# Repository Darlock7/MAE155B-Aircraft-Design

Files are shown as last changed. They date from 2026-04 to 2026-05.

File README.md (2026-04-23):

**MAE 155B Aircraft Design Project Setup and Workflow (Windows)**
Overview

**First-Time Setup on Windows**

**1.	Get Repository Access**

Make sure you have been added as a collaborator on the GitHub repository before starting.

**2.Install Git for Windows**

Link: https://github.com/git-for-windows/git/releases/download/v2.54.0.windows.1/Git-2.54.0-64-bit.exe
Download and install Git. After installation, open PowerShell and verify Git is installed by running:

	git -–version

If installed correctly, it should return a version number.

⸻

**3.	Create an SSH Key**

	mkdir $HOME.ssh
	ssh-keygen -t ed25519 -C “your_email@example.com”

Press Enter through all prompts unless you want a passphrase.

This creates:
	•	Private key: id_ed25519
	•	Public key: id_ed25519.pub

⸻

**4.Add SSH Key to GitHub**

	type $HOME.ssh\id_ed25519.pub

Copy the output.

Go to GitHub → Settings → SSH and GPG keys → New SSH key
Paste and save.

⸻

**5.Test SSH Connection**

	ssh -T git@github.com

Type “yes” if prompted.

You should see a message confirming your username.

⸻

**6.Clone the Repository**

	cd $HOME
	git clone git@github.com:Darlock7/MAE155B-Aircraft-Design.git
	cd MAE155B-Aircraft-Design

⸻

**7.Set Git Name and Email**

	git config –global user.name “Your Name”
	git config –global user.email “your_email@example.com”

⸻

MATLAB Setup
	1.	Open the Repository

Set Current Folder in MATLAB to:

C:\Users\YourUserName\MAE155B-Aircraft-Design

⸻
**2.	Run the Project**

run_project
main

Always run run_project before main.

⸻

**MATLAB Git Configuration (CRITICAL)**

Go to: Home → Settings → MATLAB → Source Control → Git

Set the following:
	•	Enable SSH
	•	Uncheck “Use SSH agent”
	•	Public key file:
C:\Users\YourUserName.ssh\id_ed25519.pub
	•	Private key file:
C:\Users\YourUserName.ssh\id_ed25519

If this is not configured correctly, MATLAB push/pull will fail.

⸻

MATLAB GUI Workflow (Primary Method)

Before Starting Work
	1.	Open MATLAB
	2.	Navigate to the repository folder
	3.	Click Source Control → Pull

⸻

If Pull Fails

This usually means local changes would be overwritten.

Fix:
	1.	Open “View Changes”
	2.	Right-click modified file (e.g., main.m)
	3.	Choose:
	•	Discard Changes (to delete local edits)
	•	Commit Changes (to keep them)
	4.	Try Pull again

⸻

While Working
	•	Edit and save files in MATLAB
	•	Avoid renaming/moving files unless necessary

⸻

After Making Changes (Push)
	1.	Open “View Changes”
	2.	Select modified files
	3.	Enter commit message
	4.	Click Commit
	5.	Click Push

⸻

Required Daily Workflow
	1.	Open MATLAB
	2.	Pull latest changes
	3.	Run run_project
	4.	Run main
	5.	Make changes
	6.	Save files
	7.	Commit
	8.	Push

⸻

PowerShell Fallback (If MATLAB Fails)

**If MATLAB fails (push, pull, SSH issues), use:**

	cd C:\Users\YourUserName\MAE155B-Aircraft-Design
	git pull
	git add .
	git commit -m “your message”
	git push

⸻

Force Pull (Overwrite Local Changes)

If you want to completely overwrite your local files:

git fetch origin
git reset –hard origin/main

WARNING: This deletes all local changes permanently.

⸻

Common Problems
	1.	Git not recognized
Fix: reinstall Git and restart PowerShell.
	2.	Permission denied (publickey)
Fix: verify your SSH key:

type $HOME.ssh\id_ed25519.pub

Ensure it matches GitHub.
	3.	MATLAB cannot connect to SSH agent
Fix: disable SSH agent in MATLAB and manually set key paths.
	4.	Push rejected (remote ahead)
Fix:

git pull

Resolve conflicts if needed, then:

git push
	5.	Merge conflicts
Look for markers like:

<<<<<<< HEAD

Fix the file, then:

git add filename
git commit -m “resolve conflict”
git push

⸻

Best Practice
	•	Use MATLAB GUI for pull, commit, and push
	•	Always pull before starting work
	•	Use PowerShell if MATLAB fails
	•	Do not edit files directly on GitHub unless necessary
	•	Do not commit generated files

⸻

Final Note

This workflow ensures MATLAB GUI works reliably on Windows. PowerShell is always the fallback when GUI operations fail.

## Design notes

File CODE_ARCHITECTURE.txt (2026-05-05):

================================================================================
  MAE 155B AIRCRAFT DESIGN — CODE ARCHITECTURE GUIDE
  Team: Harshil Patel, John Sigafoos, Angel Ochoa, Juan Sanchez,
        Sara Chowdhury, Analisa Veloz
  Last updated: May 2026
================================================================================

This document explains how the codebase is organized, what each file does,
and how data flows from one function to the next. It is written for teammates
who understand the aerodynamics and physics but are less familiar with the
MATLAB code structure.

--------------------------------------------------------------------------------
  QUICK START — HOW TO RUN THE CODE
--------------------------------------------------------------------------------

1. Open MATLAB and set the working directory to the repo root:
      MAE155B-Aircraft-Design/

2. Run:  main.m

   That is the only file you ever need to run manually. It calls everything else.

3. At the top of main.m there are RUN FLAGS (around line 74). These toggle
   optional subsections:

      showPlots      = true/false   — enable/disable all plots
      viewGeometry   = true/false   — open AVL 3D geometry viewer
      runOptimizer   = true/false   — run CMA-ES profit optimizer (6–10 hrs)
      runMonteCarlo  = true/false   — run Monte Carlo sensitivity analysis
      runSweep       = true/false   — run dynamic stability parameter sweep
      runCSopt       = true/false   — run control surface optimizer

   For a quick check run, set all flags to false except showPlots.

--------------------------------------------------------------------------------
  DIRECTORY STRUCTURE
--------------------------------------------------------------------------------

MAE155B-Aircraft-Design/
│
├── main.m                        ← PRIMARY ENTRY POINT. Run this.
├── run_project.m                 ← Adds all src/ folders to MATLAB path
│
├── src/                          ← All analysis functions
│   ├── aerodynamics/             ← Airfoil and aircraft aero
│   ├── geometry/                 ← Wing, fin, fuselage geometry
│   ├── Stability/                ← Static and dynamic stability
│   ├── propulsion/               ← Motor and propeller models
│   ├── energy/                   ← Energy and battery sizing
│   ├── mission/                  ← Flight performance and trajectories
│   └── economics/                ← Profit scoring and optimization
│
├── plotting/                     ← Visualization functions
│
├── data/
│   ├── airfoils/                 ← Airfoil coordinate files (.dat, XFOIL format)
│   ├── models/                   ← Precomputed surrogate databases (.mat)
│   ├── propellers/               ← APC propeller performance tables (.txt)
│   └── reference/                ← CAD parameters and benchmark polars
│
├── AVL/
│   └── Nimbus/                   ← AVL executable + generated geometry files
│       ├── avl352               ← AVL binary (macOS)
│       ├── avl.exe              ← AVL binary (Windows)
│       ├── fw_dyn.avl           ← Flying-wing geometry (auto-generated)
│       ├── fw_dyn.mass          ← CG / inertia input (auto-generated)
│       └── fw_dyn_st.txt        ← Stability output parsed by MATLAB
│
└── outputs/                      ← Generated results (gitignored on some branches)
    ├── main_output.txt
    ├── manufacturing_dimensions.txt
    └── profit_opt_result.mat

--------------------------------------------------------------------------------
  HOW main.m IS ORGANIZED — EXECUTION ORDER
--------------------------------------------------------------------------------

main.m runs top-to-bottom. Here is every major section in order:

  SECTION 1  — Physical constants (g, rho, mu)
  SECTION 2  — User inputs: efficiency, L/D assumption, payload weight/volume,
                mission parameters (range, altitude, cruise speed)
  SECTION 3  — CAD design variables: AR, taper, sweep, fuselage airfoil choice
  SECTION 4  — Drag build-up inputs: fuselage dimensions, wetted areas
  SECTION 5  — Package volume penalty on fe (empty weight fraction)
  SECTION 6  — Derive gross weight Wg and empty weight We from fe and payload
  SECTION 7  — Cargo bay geometry (how big a box fits inside the fuselage airfoil)
  SECTION 8  — Mission energy calculation (climb + cruise + reserve)
  SECTION 9  — Competition profit score J(x) — first-pass using assumed L/D
  SECTION 10 — Mission profile (lap geometry, runway, climb/descent distances)
  SECTION 11 — Propulsion analysis (thrust curve from motor KV + APC propeller)
  SECTION 12 — CTOL preliminary sizing (wing loading vs. thrust-to-weight diagram)
  SECTION 13 — Monte Carlo sensitivity analysis (optional)
  SECTION 14 — Design lift coefficient at cruise
  SECTION 15 — Wing geometry (span, root/tip chord, MAC, control surface coords)
  SECTION 16 — Airfoil analysis (load surrogate database, evaluate at cruise Re)
  SECTION 17 — Airfoil polar plots
  SECTION 18 — Twist function (Panknin method for required washout)
  SECTION 19 — Vertical stabilizer / winglet geometry
  SECTION 20 — Spanwise aerodynamic estimate (lift distribution)
  SECTION 21 — Aircraft drag polar (CD0 build-up, CL vs alpha, L/D)
  SECTION 22 — Aircraft mass properties (CG, inertia tensor from all components)
  SECTION 23 — Unloaded (no payload) CG and mass
  SECTION 24 — CG position as % MAC
  SECTION 25 — Updated performance state (actual stall speed, cruise speed)
  SECTION 26 — Static stability analysis (neutral point, static margin %)
  SECTION 27 — 3D geometry plot
  SECTION 28 — V-n diagram (maneuver envelope)
  SECTION 29 — Gust load overlay
  SECTION 30 — Dynamic stability via AVL (eigenvalues, short period, phugoid,
                Dutch roll, roll subsidence, spiral mode)
  SECTION 31 — SM correction advisor (where to move the battery for target SM)
  SECTION 32 — Control surface sizing (trim deflection, max load factor, turn radius)
  SECTION 33 — Control surface optimizer (optional)
  SECTION 34 — Dynamic stability sweep (optional)
  SECTION 35 — CMA-ES profit optimizer (optional, 6–10 hrs)
  SECTION 36 — Structure sizing
  SECTION 37 — Profit re-evaluation with actual physics (final sanity check)

--------------------------------------------------------------------------------
  WHAT EACH SOURCE FILE DOES
--------------------------------------------------------------------------------

---- AERODYNAMICS (src/aerodynamics/) ----

  aeroPolarAircraft.m
    Input:  wing geometry (AR, Sref, MAC, sweep), airfoil data (Cla, alphaL0,
            Clmax, Cm0 for root and tip), drag build-up inputs
    Output: aircraft CL(alpha), CD(alpha), L/D(alpha), cruise CL/CD/L-D,
            stall alpha, CDo breakdown (wing/body/fin)
    What it does: Builds the whole-aircraft drag polar using the parabolic
    model CD = CD0 + CL²/(pi*e*AR). CD0 is computed from a Raymer-style
    skin-friction and form-factor drag build-up.

  loadAirfoilSurrogateDB.m
    Input:  repoRoot (path to repo)
    Output: airfoilDB struct
    What it does: Loads data/models/airfoilDB.mat into MATLAB. This .mat file
    contains precomputed XFOIL results for all airfoils at many Reynolds numbers.

  evaluateAirfoilSurrogate.m
    Input:  airfoilDB, airfoil name (e.g. 'e222.dat'), Reynolds number
    Output: Cla, alphaL0, Cm0, Clmax, best L/D interpolated at that Re
    What it does: Interpolates from the precomputed database so we do not need
    to run XFOIL at runtime (which is slow and can fail).

  buildAirfoilSurrogates.m
    What it does: Offline tool — runs XFOIL on every airfoil in data/airfoils/
    across a grid of Reynolds numbers and saves airfoilDB.mat. Only needs to
    be re-run if you add a new airfoil.

  twistFunctionPanknin.m
    Input:  b, AR, c_root, c_tip, sweep, alphaL0 root/tip, Cm0 root/tip,
            CL_design, twist_root_deg (user-set washout at root)
    Output: full spanwise twist distribution, geometric and aerodynamic twist
    What it does: Uses the Panknin method (from class slides) to compute how
    much twist the wing needs across the span to satisfy the pitching moment
    and lift requirements. The optimizer controls twist_root_deg; this function
    computes the required tip twist.

  spanwiseAeroEstimate.m
    Input:  wing geometry + twist distribution + airfoil properties
    Output: spanwise section CL, local lift, root/tip effective alpha
    What it does: Piecewise estimate of how lift is distributed along the span.

---- GEOMETRY (src/geometry/) ----

  wingGeometryDesign.m
    Input:  S_ref [m²], AR, taper ratio, sweep_c4 [deg], xLE_root, y_root
    Output: b, c_root, c_tip, MAC, xLE_tip, xLE_MAC, x_c4_MAC, semiSpan,
            control surface geometry (span stations, area)
    What it does: From the four main planform parameters, computes every chord,
    position, and sweep angle you need. This is the source of truth for all
    geometric quantities used downstream.

  verticalSurfaceDesign.m
    Input:  AR_v, taper_v, sweep_c4_v, tail volume coefficient c_v,
            wing reference geometry (for moment arm)
    Output: S_v, b_v, c_root_v, c_tip_v, MAC_v, all LE/TE positions,
            rudder geometry
    What it does: Sizes the winglet/vertical stabilizer using a tail volume
    coefficient approach, then computes the full trapezoidal fin geometry.

  cargoBayGeometry.m
    Input:  Lf (fuselage length), Wf (fuselage width), airfoil file
    Output: maximum rectangle width and height that fits inside the airfoil
            cross-section, cargo bay volume [m³]
    What it does: Finds the largest rectangular box that fits inside the
    fuselage airfoil shape. Volume = cross-section area × spanwise depth (Wf).

---- STABILITY (src/Stability/) ----

  dynamicStabilityAVL.m
    Input:  mass, inertia tensor, CG, wing geometry, fin geometry, aero data,
            cruise conditions
    Output: full eigenvalue set, mode damping ratios and frequencies,
            handling quality level (MIL-STD), control derivatives
    What it does: This is the most complex function. It:
      1. Writes the AVL geometry file (.avl) from MATLAB inputs
      2. Writes the mass/inertia file (.mass)
      3. Runs the AVL binary (avl352 on Mac, avl.exe on Windows) via system()
      4. Parses AVL's stability derivative output (CL_alpha, Cm_alpha, Cm_q, etc.)
      5. Performs eigenanalysis to find the 4 longitudinal and 4 lateral modes
      6. Classifies modes: Short Period, Phugoid, Dutch Roll, Roll Subsidence, Spiral
      7. Rates handling qualities per MIL-STD-1797 (Level 1/2/3)

  aircraftMassProperties.m
    Input:  cadBodies (CAD-derived mass components), pointMasses (discrete items:
            motor, battery, receiver, payload, servos, etc.)
    Output: total mass, CG [x,y,z], full 3×3 inertia tensor about CG
    What it does: Combines all mass contributions and applies the parallel-axis
    theorem to compute the inertia tensor about the aircraft CG.

  staticStabilityAnalysis.m
    Input:  CG position, neutral point, MAC, xLE_MAC
    Output: static margin [%], stability band check, CG shift with/without payload
    What it does: Computes SM = (x_NP - x_CG) / MAC. The neutral point in this
    function comes from the simplified assumption x_NP = x_c4_MAC (25% MAC).
    Note: AVL gives a more accurate neutral point — trust AVL's SM over this one.

  makePointMass.m
    Input:  name (string), mass [kg], position [x, y, z] [m]
    Output: struct with those fields
    What it does: Simple helper to create a component entry for mass properties.
    Used throughout main.m to define motor, battery, payload, servos, etc.

  controlSurfaceSizing.m
    Input:  AVL control derivatives (Cmde, Clda, Cnda, Clp), cruise conditions,
            wing geometry, mass
    Output: trim elevon deflection, max load factor, min turn radius, roll rate,
            hinge moments for servo sizing
    What it does: Converts AVL's dimensionless derivatives into real performance
    numbers — how many degrees the elevon must deflect to trim, how fast it rolls.

---- PROPULSION (src/propulsion/) ----

  propulsionAnalysis.m
    Input:  motor KV [RPM/V], Rm [ohm], I0 [A], battery voltage,
            propeller name (e.g. '10x4.5MR'), speed vector V_vec
    Output: thrust curve T(V), power curve P(V), static thrust T_static,
            static current
    What it does: Uses the APC propeller data tables in data/propellers/ plus
    the motor electrical model (back-EMF) to compute how much thrust the
    motor/prop combination produces at any flight speed.

---- ENERGY (src/energy/) ----

  energyCalc.m
    Input:  Wg [N], eta_p (propulsion efficiency), LD (lift-to-drag),
            delta_h [m] (climb altitude), R_cruise [m], reserve_factor
    Output: E_climb, E_cruise, E_f (total mission energy), E_design (with reserve)
    What it does: Simple physics energy calculation.
      E_climb  = Wg * delta_h / eta_p
      E_cruise = (Wg / LD) * R_cruise / eta_p
    These are used directly in the profit function.

---- MISSION (src/mission/) ----

  missionProfileCigar.m
    Input:  runway length, pattern dimensions, cruise speed, climb/descent angles
    Output: lap length, flight times for each phase, liftoff/touchdown positions
    What it does: Models the "cigar-shaped" competition course (two straights
    connected by 180° turns) and computes total mission geometry.

  solveCruiseSpeed.m
    Input:  rho, weight, Sref, drag polar, thrust curve
    Output: actual cruise speed where T_available = D
    What it does: Finds the speed where the propeller thrust equals the aircraft
    drag. This is the actual cruise speed, which may differ from the design speed.

  updatePerformanceState.m
    Input:  all aerodynamic and propulsion data
    Output: actual stall speed, takeoff speed, cruise speed, max climb rate
    What it does: Given the fully-computed aircraft (not the simplified early
    estimate), re-derives all performance numbers for a final sanity check.

---- ECONOMICS (src/economics/) ----

  profitPerUnitTime.m
    Input:  Wp [N] (payload weight), Vp [m³] (payload volume),
            Ef [J] (total energy × 20 flights), Wg [N], Tf [s] (time × 20 flights)
    Output: J [$/s] — competition profit score
    What it does: Implements the MAE155B competition scoring function exactly.
    This is the number you want to maximize. J increases with heavier payload,
    more payload volume, and lighter/more efficient aircraft.

  profitOptimization.m
    Input:  optIn struct with all mission/physics context + bounds + settings
    Output: optimal design vector (13 variables), best J achieved, convergence history
    What it does: Runs CMA-ES (Covariance Matrix Adaptation Evolution Strategy),
    a gradient-free global optimizer, to find the combination of AR, taper, sweep,
    twist, wing loading, fuselage size, fin shape, and cruise speed that maximizes J.
    Each candidate design calls wingGeometryDesign → airfoil surrogate → twist →
    vertical surface → mass model → drag polar → AVL stability → profit score.
    Constraints enforced: stall speed ≤ 12 m/s, static margin 5–13%,
    takeoff ground roll ≤ 138 m, climb T/W feasible, turn T/W feasible,
    winglet chord ≤ 1.2× wing tip chord, wingspan ≤ 2.5 m.
    Runtime: 6–10 hours on a fast machine with parallel workers.

  monteCarloProfitSensitivity.m
    Input:  baseline design + uncertainty ranges for each variable
    Output: distribution of J, sensitivity to each parameter
    What it does: Randomly perturbs design variables within tolerances and
    computes J for each sample. Shows which parameters most affect profit.

---- PLOTTING (plotting/) ----

  plotAircraftGeometry3D.m
    What it does: Draws the full 3D aircraft — wing, fins, fuselage, CG markers
    (loaded and unloaded), and component point masses. Most useful visual check.

  preliminarySizingCTOL.m
    What it does: Draws the T/W vs W/S carpet plot showing stall, climb, turn,
    and takeoff constraint lines. The design point sits where all constraints
    are satisfied with minimum T/W.

  plotVNDiagram.m
    What it does: Draws the velocity-load factor (V-n) diagram showing the
    maneuver envelope, stall boundary, and gust load curves.

--------------------------------------------------------------------------------
  DATA FLOW SUMMARY
--------------------------------------------------------------------------------

This shows what each function needs from others:

  Inputs (user)
       |
       v
  wingGeometryDesign  ──────────────────────────────────────────────────────┐
       |  b, c_root, c_tip, MAC, xLE positions                              |
       v                                                                     |
  evaluateAirfoilSurrogate (uses airfoilDB.mat at cruise Re)               |
       |  Cla, alphaL0, Cm0, Clmax for root and tip                        |
       v                                                                     |
  twistFunctionPanknin                                                      |
       |  spanwise twist distribution                                        |
       v                                                                     |
  aeroPolarAircraft                                                         |
       |  CL(alpha), CD(alpha), L/D, cruise CL/CD, CD0 breakdown           |
       v                                                                     |
  energyCalc(Wg, L/D, ...)     propulsionAnalysis(motor, prop, ...)        |
       |  E_climb, E_cruise             |  T(V) thrust curve                |
       v                               v                                    |
  profitPerUnitTime(Wp, Vp, Ef, Wg, Tf)                                    |
       |  J [$/hr]                                                           |
       v                                                                     |
  (optimization target)                                                     |
                                                                            |
  aircraftMassProperties(all components)  ◄──── verticalSurfaceDesign ◄───┘
       |  total mass, CG, inertia tensor
       v
  dynamicStabilityAVL(geometry + mass + aero)
       |  eigenvalues, damping, frequencies, SM from AVL
       v
  controlSurfaceSizing(AVL derivatives + geometry)
       |  trim deflection, max load factor, servo hinge moments
       v
  updatePerformanceState(aero + propulsion + mass)
       |  actual stall speed, actual cruise speed, climb rate
       v
  [Final output to screen + plots]

--------------------------------------------------------------------------------
  THE OPTIMIZATION LOOP (profitOptimization.m)
--------------------------------------------------------------------------------

Every time the optimizer evaluates one candidate design, it runs this
internal mini-pipeline:

  1. Decode 13 design variables from normalized [0,1] space to physical units
  2. Estimate gross weight from empty-weight fraction model
  3. wingGeometryDesign  → planform
  4. Evaluate airfoil surrogates at cruise Re for root and tip
  5. twistFunctionPanknin → required washout
  6. verticalSurfaceDesign → fin geometry
  7. Check geometric feasibility (tip chord, wingspan, fin height, fin chord)
  8. Scale structural masses
  9. aircraftMassProperties → CG + inertia
  10. aeroPolarAircraft → L/D and CD0
  11. Check stall speed ≤ 12 m/s
  12. Check takeoff ground roll ≤ 138 m
  13. Check climb T/W feasible at V_climb = 13 m/s
  14. Check turn T/W feasible at V_turn = 13 m/s
  15. dynamicStabilityAVL → static margin
  16. Check SM in [5%, 13%] band
  17. energyCalc + profitPerUnitTime → J
  18. Apply soft penalties for poor dynamic stability modes
  19. Return -J as the objective (CMA-ES minimizes, we maximize J)

  If any hard constraint (steps 7–16) is violated, the design is rejected
  immediately (returns 1e6) without computing J. This saves time.

  With lambda ≈ 26 candidates per generation and 500 generations,
  the optimizer evaluates ~13,000 designs. Each design takes ~2 s
  (dominated by AVL). Total runtime: 6–10 hours with parfor.

--------------------------------------------------------------------------------
  AVL INTEGRATION
--------------------------------------------------------------------------------

AVL (Athena Vortex Lattice) is an external program by Mark Drela (MIT).
It computes aerodynamic stability derivatives using a vortex-lattice method,
which is significantly more accurate than our simplified analytical formulas.

How MATLAB uses AVL:

  1. dynamicStabilityAVL.m writes three files based on the current design:
       AVL/Nimbus/fw_dyn.avl    ← geometry: wing panels, fin panels, control deflections
       AVL/Nimbus/fw_dyn.mass   ← mass, CG location, inertia tensor
       AVL/Nimbus/fw_dyn.run    ← operating condition: V, rho, alpha_trim

  2. MATLAB calls:   system('./avl352 < fw_dyn_cmd.txt > fw_dyn_st.txt')
     This runs AVL, feeds it commands via the .txt file, and captures output.

  3. MATLAB reads fw_dyn_st.txt and parses numbers using regular expressions:
       CLa, Cma (lift and pitch moment slopes)
       Cmq      (pitch damping)
       CYb, Clb, Cnb (lateral-directional derivatives)
       Eigenvalues (complex pairs for longitudinal and lateral modes)

  4. From the eigenvalues, MATLAB classifies each mode:
       Short Period:   high-frequency, well-damped pitch oscillation (want zeta > 0.35)
       Phugoid:        low-frequency speed/pitch exchange (want zeta > 0)
       Dutch Roll:     coupled yaw-roll oscillation (want zeta*wn > 0.19)
       Roll Subsidence: first-order roll decay (want tau < 1.0 s)
       Spiral:         slow roll divergence (want t_half > 20 s)

  Important: The "Static Margin" reported by AVL is the authoritative value.
  The simpler static margin in the main.m static stability section uses a
  rough neutral point at 25% MAC, which is less accurate.

--------------------------------------------------------------------------------
  AIRFOIL SURROGATE DATABASE
--------------------------------------------------------------------------------

Running XFOIL every time would be too slow (2–5 s per airfoil per Re).
Instead, we precompute all results offline:

  buildAirfoilSurrogates.m  ← run once, saves data/models/airfoilDB.mat

At runtime, main.m calls:
  loadAirfoilSurrogateDB(repoRoot)  ← loads the .mat file (fast)
  evaluateAirfoilSurrogate(db, 'e222.dat', Re_root)  ← interpolates at Re

The database stores for each airfoil at each Reynolds number:
  Cla        [1/deg]   — lift curve slope
  alphaL0    [deg]     — zero-lift angle of attack
  Cm0        [-]       — pitching moment at zero lift
  Cl_max     [-]       — maximum lift coefficient
  best_LD    [-]       — maximum L/D

The optimizer uses this database internally so AVL calls (not XFOIL) are the
bottleneck during optimization.

--------------------------------------------------------------------------------
  ADDING A NEW AIRFOIL
--------------------------------------------------------------------------------

1. Put the airfoil .dat file in data/airfoils/ (XFOIL format: two columns x/c, y/c)

2. Open buildAirfoilSurrogates.m and add the filename to the airfoil list

3. Run buildAirfoilSurrogates.m once — this regenerates airfoilDB.mat

4. In main.m, change:
      airfoilRootName = 'your_new_airfoil.dat';
   or
      airfoilTipName  = 'your_new_airfoil.dat';

5. For the fuselage airfoil, add an entry to the airfoilFileMap struct in main.m
   and change fuselageAirfoil = 'your_new_airfoil_name';

--------------------------------------------------------------------------------
  MASS PROPERTIES — HOW COMPONENTS ARE DEFINED
--------------------------------------------------------------------------------

Every physical object on the aircraft is entered as either:

  (a) A CAD body from massIn.cadBodies:
      These come from Onshape. Each CAD body has a measured mass and CG
      from the CAD model. The cadMass struct is populated near the top of
      the mass properties section in main.m.

  (b) A discrete point mass using makePointMass():
      comp(end+1) = makePointMass('Motor', 0.085, [0.0, 0.0, 0.0]);
      comp(end+1) = makePointMass('Battery', 0.150, [0.551, 0.0, -0.009]);
      comp(end+1) = makePointMass('Payload', 0.800/9.81*9.81, [x, y, z]);
      Arguments: name (string), mass [kg], position [x, y, z] in meters
                 x=0 is motor, x increases aft toward tail

  aircraftMassProperties() combines all of these, applies the parallel-axis
  theorem, and returns the total mass, CG, and inertia tensor.

  To move the battery for static margin correction:
  Find the line with 'B1 Main Battery' and change the x-coordinate.
  The SM Correction Advisor at the bottom of main.m tells you what x to use.

--------------------------------------------------------------------------------
  UNITS CONVENTION
--------------------------------------------------------------------------------

  All quantities in SI unless otherwise noted.
  Length:      meters [m]
  Mass:        kilograms [kg]
  Force:       Newtons [N]
  Angle:       degrees [deg] at input/output; radians inside stability functions
  Speed:       meters per second [m/s]
  Pressure:    Pascals [Pa]
  Energy:      Joules [J]
  Power:       Watts [W]
  Area:        square meters [m²]
  Volume:      cubic meters [m³]  (multiply by 1000 for liters)
  Profit J:    dollars per second [$/s]  (multiply by 3600 for $/hr)

  The competition scoring function expects:
    Ef in [J] (total energy over 20 flights)
    Tf in [s] (total time over 20 flights)
  The x20 scaling is applied in main.m before calling profitPerUnitTime().

--------------------------------------------------------------------------------
  COMMON DEBUGGING TIPS
--------------------------------------------------------------------------------

Q: main.m crashes with "file not found" on airfoilDB.mat
A: Run buildAirfoilSurrogates.m once to generate the database.

Q: AVL gives wrong static margin
A: Check that the battery x-position in the mass properties section matches
   what the SM Correction Advisor recommends. Also verify that the .mass file
   CG printed in the AVL output matches main.m's aircraftMassProperties output.

Q: Optimizer returns -$1.94/hr or clearly wrong results
A: Workers have cached old bytecode. Run:
     delete(gcp('nocreate')); clear functions;
   before profitOptimization(). This is already in main.m when runOptimizer=true.

Q: Stall speed is above 12 m/s
A: Wing loading W/S is too high. Either increase S_ref (lower WS in optimizer
   bounds) or reduce gross weight.

Q: Feasible@climb = 0 in CTOL sizing
A: Check that V_climb in the mission struct is above the design stall speed.
   The CTOL sizing code checks thrust at V_climb against the T/W required for
   the governing constraint — if V_climb < V_stall, the aircraft cannot fly
   at that speed and the check fails.

Q: "pattern not found: CDa" warning from dynamicStabilityAVL
A: This is cosmetic. AVL does not output CDa in all run configurations.
   The code handles this gracefully and the warning does not affect results.

--------------------------------------------------------------------------------
  DESIGN VARIABLES CONTROLLED BY THE OPTIMIZER
--------------------------------------------------------------------------------

  Index  Variable             Units   Lower  Upper
  ─────  ─────────────────────────────────────────────────────
    1    AR                   [-]     4.0    10.0
    2    Taper ratio          [-]     0.50   0.80
    3    Wing sweep (c/4)     [deg]   0.0    35.0
    4    Root twist           [deg]  -3.0   -1.0    (forced washout)
    5    Wing loading W/S     [N/m²]  20.0   90.0
    6    xLE root             [m]     0.030  0.300
    7    Vertical fin AR      [-]     2.00   2.50
    8    Vertical fin taper   [-]     0.30   0.70
    9    Vertical fin sweep   [deg]   20.0   45.0
   10    Cruise speed         [m/s]   20.0   28.0
   11    Payload volume Vp    [m³]    0.001  0.030
   12    Fuselage half-width  [m]     0.050  0.200
   13    Fuselage length      [m]     0.600  1.000

  When the optimizer finishes, it prints a block labeled
  "--- Update main.m with these values ---"
  Copy those values into the corresponding lines in main.m and re-run.

================================================================================
  END OF DOCUMENT
================================================================================

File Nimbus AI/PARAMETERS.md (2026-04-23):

# Aircraft Design Parameters

This file is the single source of truth for all fixed design parameters, measured values, and data file references. Update it as new information becomes available. Claude reads this before any physics analysis or code work.

All values sourced from `main.m` unless otherwise noted.

---

## Mission Requirements

| Parameter | Value | Unit | Notes |
|---|---|---|---|
| Payload mass | 800 | g | Wp_g |
| Payload weight | 7.848 | N | Wp = (800/1000) × 9.81 |
| Payload volume (actual) | 0.002 | m³ | Vp |
| Payload volume (reference) | 0.001 | m³ | Vp_ref — penalty baseline |
| Volume scaling ratio (VPS) | 2.0 | — | Vp / Vp_ref |
| Cruise speed | 20 | m/s | V_cruise |
| Cruise range | 18000 | m | R_cruise |
| Climb altitude | 120 | m | delta_h |
| Flight time (measured, 1 lap) | 61 | s | Tf_measured |
| Number of competition laps | 3 | — | mission.nLaps |
| Competition score scaling | ×20 | — | Ef and Tf scaled ×20 for scoring |

---

## Competition / Field Geometry

| Parameter | Value | Unit | Notes |
|---|---|---|---|
| Runway length | 138.35 | m | mission.runwayLength_m |
| Lap length target | 407.103 | m | mission.lapLengthTarget_m |
| Straight length | 140.0 | m | mission.straightLength_m |
| Liftoff fraction of runway | 0.85 | — | mission.liftoffFrac |
| Touchdown fraction | 0.333 | — | mission.touchdownFrac |
| Cruise altitude | 30 | m | mission.h_cruise |
| Competition site | SeaWorld, San Diego | — | June flight conditions |

---

## Aircraft Weight Budget

| Parameter | Value | Unit | Notes |
|---|---|---|---|
| Propulsion system weight | 2.43341 | N | Wprop — measured |
| Empty weight fraction (baseline) | 0.450 | — | fe |
| Empty weight fraction (max cap) | 0.60 | — | fe_max |
| L/D penalty slope | 0.02 | — | kd per unit VPS beyond reference |
| Empty-wt penalty slope | 0.0375 | — | ke = fe/12 per unit VPS |
| Propulsion efficiency | 0.75 | — | eta_p |
| Energy reserve factor | 1.15 | — | reserve_factor |

---

## Aerodynamics

| Parameter | Value | Unit | Notes |
|---|---|---|---|
| Aspect ratio (AR) | 8.5 | — | CAD design variable |
| Wing taper ratio | 0.85 | — | wingTapper |
| Wing sweep (c/4) | 30 | deg | wingSweep |
| Oswald efficiency (e) | 0.80 | — | first-pass |
| Parasite drag (CD0) | 0.030 | — | first-pass; updated by drag build-up |
| CLmax | 1.8 | — | first-pass; updated by drag build-up |
| L/D (baseline) | 20 | — | LD; penalized by VPS |
| Root airfoil | e222.dat | — | Eppler 222 |
| Tip airfoil | e230.dat | — | Eppler 230 |
| Reference AoA (spanwise estimate) | 6.5 | deg | spanIn.alpha_ref_deg |
| Static margin target | 10–20 | % MAC | stabIn.SM_target_min/max |

---

## Mission Profile (Climb / Descent)

| Parameter | Value | Unit | Notes |
|---|---|---|---|
| Climb speed | 14.0 | m/s | mission.V_climb_mps |
| Climb angle | 11.0 | deg | mission.gamma_climb_deg |
| Descent speed | 25.0 | m/s | mission.V_descent_mps |
| Descent angle | 12.0 | deg | mission.gamma_descent_deg |
| Turn load factor | 1.6 | — | mission.n_turn |

---

## Propulsion

| Parameter | Value | Unit | Notes |
|---|---|---|---|
| Motor KV | 1100 | RPM/V | propIn.KV |
| Motor resistance (Rm) | 0.073 | Ω | propIn.Rm |
| No-load current (I0) | 0.9 | A | propIn.I0 |
| Battery voltage | 11.1 | V | 3S LiPo |
| Max current | 35 | A | propIn.I_max |
| Propeller | 10×4.5MR | — | APC propeller |
| Propeller diameter | 10 | in | propIn.D_in |
| Propeller pitch | 4.5 | in | propIn.pitch_in |

---

## Geometry (CAD-Derived)

All values from OnShape CAD model unless noted.

| Parameter | Value | Unit | Notes |
|---|---|---|---|
| Wing root LE x-location | 0.0822 | m | Imported OnShape 4/21/2026 |
| Wing root y-location | 0.145 | m | Imported OnShape 4/20/2026 |
| Body length (Lf) | 0.5567 | m | Drag build-up input |
| Body max width (Wf) | 0.1664 | m | Drag build-up input |
| Body max height (Hf) | 0.1015 | m | Drag build-up input |
| Wing wetted area | 0.50845 | m² | Swet_wing — from CAD |
| Fuselage wetted area | 0.20136 | m² | Swet_fuse — from CAD |
| Fin wetted area (total) | 0.10996 | m² | Swet_fin — from CAD |
| Thickness-to-chord ratio (t/c) | 0.12 | — | tc — representative |
| x/c at max thickness | 0.30 | — | xc |
| Interference factor (wing) | 1.10 | — | Q_wing |
| Interference factor (fuse) | 1.10 | — | Q_fuse |
| Interference factor (fin) | 1.10 | — | Q_fin |

---

## Mass Properties

| Component | Mass | Unit | Notes |
|---|---|---|---|
| Fuselage (CAD) | 0.605 | kg | cadMass.fuselageOnly — replace with final CAD |
| Fuselage CG | [0.2699, 0.0, 0.0209] | m | cadMass.fuselageOnly.cg_m |
| Wing structure (both halves) | 0.392 | kg | First-pass placeholder |
| Vertical structure (both fins) | 0.040 | kg | First-pass placeholder |
| Main motor | 0.085 | kg | |
| Main propeller | 0.020 | kg | |
| ESC | 0.051 | kg | |
| Battery | 0.300 | kg | At x = 0.33 m — movable for CG tuning |
| Receiver | 0.015 | kg | |
| Each servo (×5) | 0.009 | kg | Wing ×2, back wing ×1, vert stab ×1, cargo ×1 |

---

## Atmosphere & Environment

| Parameter | Value | Unit | Notes |
|---|---|---|---|
| Air density (ρ) | 1.19 | kg/m³ | June, near SeaWorld San Diego |
| Dynamic viscosity (μ) | 1.789×10⁻⁵ | kg/(m·s) | Standard sea level |
| Mach number (cruise) | ~0.06 | — | V=20 m/s, incompressible flow |

---

## Structures (First-Pass)

| Parameter | Value | Unit | Notes |
|---|---|---|---|
| Allowable stress (carbon fiber) | 200 | MPa | sigma_allow |
| Young's modulus (carbon fiber) | 70 | GPa | E |
| Carbon fiber density | 1600 | kg/m³ | rho_cf |
| Safety factor | 2.0 | — | SF |
| Selected spar diameter | 10 | mm | d_selected — solid circular CF spar |
| Landing drop height (assumed) | 0.3 | m | h_drop |

---

## V-n Diagram

| Parameter | Value | Unit | Notes |
|---|---|---|---|
| Positive limit load factor | 3.8 | — | n_pos_limit |
| Negative limit load factor | -1.5 | — | n_neg_limit |
| Gust velocity at Vc | 30 | ft/s | Ude_Vc_fps — first-pass |
| Gust velocity at Vd | 15 | ft/s | Ude_Vd_fps — first-pass |
| Dive speed | 1.25 × Vc | m/s | First-pass assumption |

---

## Vertical Stabilizer

| Parameter | Value | Unit | Notes |
|---|---|---|---|
| Configuration | Twin fin | — | isTwin = true |
| Sizing method | Tail volume coeff | — | sizeMode = 'tailVolumeCoeff' |
| Vertical tail volume coeff (c_v) | 0.04 | — | Total system |
| Fin aspect ratio | 2.0 | — | AR_v |
| Fin taper ratio | 0.60 | — | taper_v |
| Fin quarter-chord sweep | 30.0 | deg | sweep_c4_v_deg |
| Fin airfoil | NACA0010 | — | |
| Top area fraction | 0.66 | — | topFrac |

---

## Data Files

Excel files and datasets stored in `data/`. Add entries here as files are added.

| File | Location | Description |
|---|---|---|
| all_prop_surrogates.mat | `data/propellers/` | APC propeller surrogate model (used by propulsionAnalysis) |
| e222.dat | root of repo | Eppler 222 airfoil coordinates |
| e230.dat | root of repo | Eppler 230 airfoil coordinates |

---

## Computed Outputs (from last main.m run — 2026-04-22)

| Parameter | Value | Unit |
|---|---|---|
| Gross weight (Wg) | 20.061 | N |
| Gross weight | 2044.98 | g |
| Empty weight (We) | 9.780 | N |
| Wing area (S_ref) | 0.2083 | m² |
| Full span (b) | 1.3307 | m |
| Root chord | 0.1692 | m |
| Tip chord | 0.1439 | m |
| MAC | 0.1569 | m |
| Wing loading (W/S) design | 96.29 | N/m² |
| Thrust/weight design | 0.6055 | — |
| Required thrust | 12.147 | N |
| Static thrust (propulsion) | 17.766 | N |
| Climb energy (E_climb) | 3209.81 | J |
| Cruise energy (E_cruise) | 24555.02 | J |
| Total mission energy (E_f) | 27764.82 | J = 7.71 Wh |
| Design energy w/ reserve | 31929.55 | J = 8.87 Wh |
| Profit score J | 0.000472 | $/s = 1.70 $/hr |
| Root Cl_alpha | 0.12129 | per deg |
| Root alphaL0 | -2.751 | deg |
| Root Cm0 | -0.08234 | — |
| Root Cl_max | 1.208 | — |
| Tip Cl_alpha | 0.13210 | per deg |
| Tip alphaL0 | 0.393 | deg |
| Tip Cm0 | 0.02243 | — |
| Tip Cl_max | 0.797 | — |
| Aerodynamic twist | -3.145 | deg |
| Required tip geometric twist | -5.029 | deg |
| Single-fin area | 0.0276 | m² |
| Total vertical area | 0.0552 | m² |
| Fin span | 0.2350 | m |

---

## Known Issues / Flags

- `aeroPolarAircraft.m` **does not exist in the repo** — `main.m` crashes at the drag build-up section (line 871). This function needs to be created in `src/aerodynamics/` or located and moved from MATLAB Drive.
- `energyCalc.m` was previously missing but is now found after running `run_project.m` — confirmed working. — it lives on MATLAB Drive (`/Users/JuanManuelSanchez/MATLAB-Drive/MAE 155B`). Running `main.m` will fail at the energy calculation step until this is moved into `src/energy/`.
- Fuselage CAD mass and inertia tensor are marked as placeholders — replace with final OnShape export.
- Wing and vertical structure masses are first-pass estimates — update from CAD or structural sizing.
- Neutral point uses approximate wing AC only (`useApproxNP = true`) — replace with AVL result before trusting stability margins.

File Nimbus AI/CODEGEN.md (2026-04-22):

# CodeGen — Physics Code Writing Process

This is the process to follow every time new physics-based MATLAB code is written for this project. No exceptions.

---

## Phase 1 — RECEIVE

Read the prompt and identify:
- What physical phenomenon or engineering system is being modeled
- Which subsystem it belongs to (`aerodynamics`, `propulsion`, `geometry`, `stability`, `energy`, `economics`, `mission`)
- What existing functions in `src/` are already doing related work — read them before proceeding
- Which class slides are relevant — read them before writing any equations
- What inputs, outputs, and operating conditions are expected
- What is missing or ambiguous

If critical inputs or constraints are missing: ask before writing any code.  
If minor gaps exist: state the assumption explicitly and proceed.

---

## Phase 2 — PLAN

Before writing code, define:
- The governing physics: what equations will be implemented and where they come from (cite slide file)
- The function signature: name, inputs, outputs, units
- Where the file lives in the project structure
- What existing functions will be called or extended
- What assumptions are baked in and why they are valid for this project
- How the result will be validated

Do not proceed to Phase 3 until this is clear.

---

## Phase 3 — REFINE

Check the plan against:
- **Existing code** — does this duplicate or conflict with anything already in `src/`?
- **Class material** — do the equations match what was taught? If a different form is used, justify it.
- **Units** — are all quantities in SI? Are unit conversions explicit?
- **Teammate work** — does this interface correctly with functions written by others?
- **Physics sanity** — do the equations reduce to known limits? Are signs and directions consistent?

Fix the plan here, not mid-build.

---

## Phase 4 — BUILD

Write the function. Every new function must:
- Live in the correct `src/` subfolder
- Follow existing naming conventions (e.g., `camelCase`, verb-noun pattern)
- Include a header defining: purpose, inputs (name, unit, description), outputs (name, unit, description), assumptions
- Call existing project functions rather than reimplementing
- Be self-contained and runnable in isolation
- Include a suggested validation test or sanity check at the bottom (commented)

---

## Phase 5 — DONE

After delivering the code, append an `Engineering Check`:
- Assumptions that could be wrong given real operating conditions
- Physical edge cases or failure modes not handled
- Unit or dimensional analysis flags
- What should be validated before this function is trusted in the main pipeline

---

## Quick Reference

```
RECEIVE  →  understand the physics, read existing code and slides
PLAN     →  equations, signature, file location, validation strategy
REFINE   →  check against codebase, class theory, units, teammates
BUILD    →  write clean, modular, well-documented MATLAB
DONE     →  deliver + Engineering Check
```

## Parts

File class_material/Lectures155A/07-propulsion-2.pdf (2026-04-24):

# Beyond scaling laws for fuel-burning propulsion

- pyCycle is a gas-turbine cycle analysis tool that enforces mass, energy, and momentum conservation across engine components.
- Engine components are modeled explicitly (fan, compressors, turbines, burner, afterburner, ducts, nozzles) using prescribed pressure ratios, efficiencies, losses, and performance maps.
- On-design analysis sizes the engine; off-design analysis predicts performance across Mach, altitude, and throttle.
- Compared to first-order scaling laws, pyCycle adds realistic losses, choking, and spool interactions

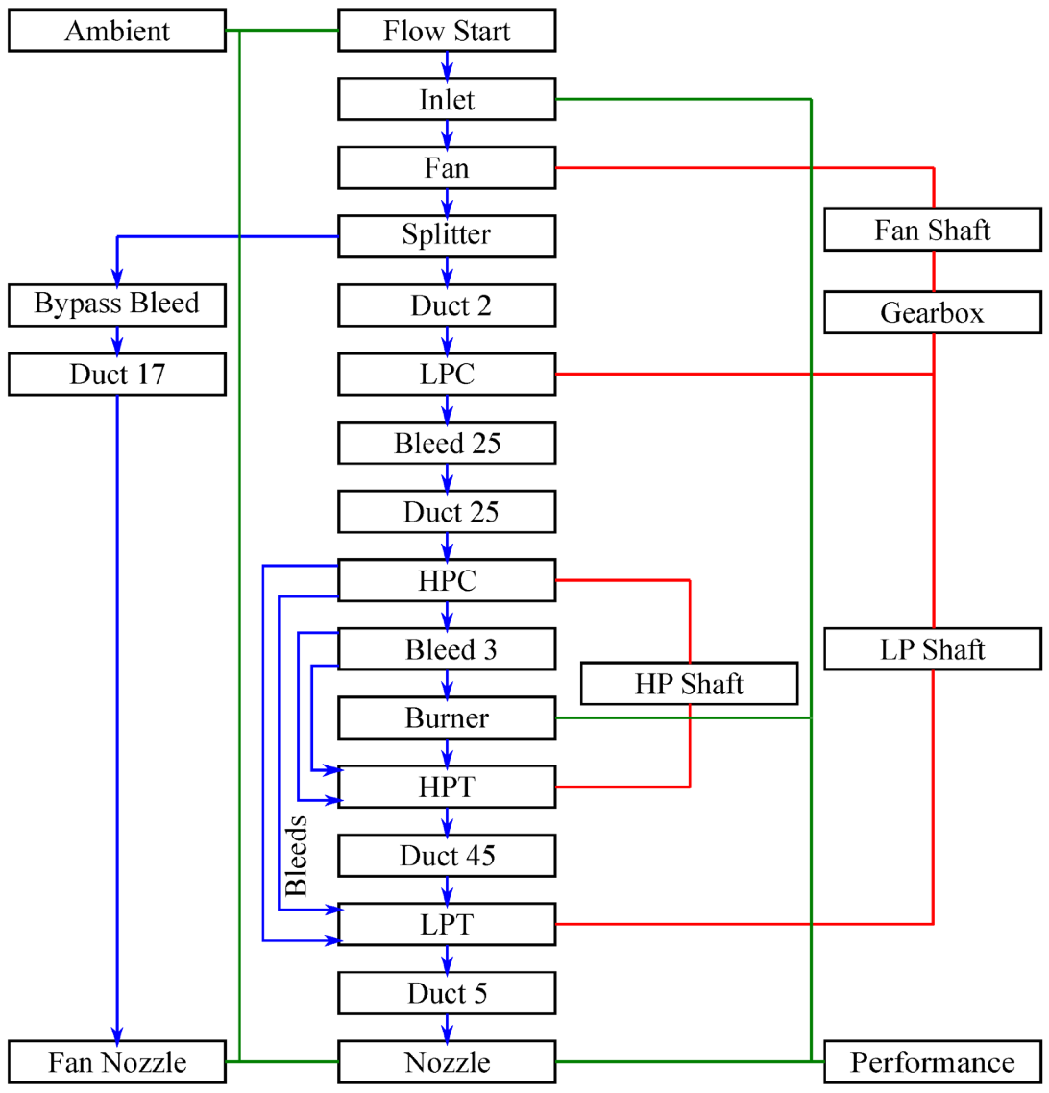
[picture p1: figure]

Hendricks, E. S., & Gray, J. S. (2019). pyCycle: A tool for efficient optimization of gas turbine engine cycles. Aerospace, 6(8), 87.

# Electric propulsion

- No emissions; more than 90% energy efficiency possible versus only 20% for gas engines
- Fewer moving parts than reciprocating or turbine engines, so greater reliability & simplicity
- Smooth and quiet
- Power does not decrease with altitude
- Can be overpowered for a short time for takeoff or emergency conditions

Batteries:
- Close to 100% charge and discharge efficiency
- Current battery energy density (specific energy): ~150 Wh/kg
- Current battery power density (specific power): ~200 W/kg
- Typically limit discharge to 20% state of charge (SOC) to protect battery life

# Propellers

Diameter or radius

Pitch / twist (radial profile)

Chord (radial distribution)

Angular speed [rad/s]

Rotational speed [rev/s]

Inflow velocity

## D R β

c
| ω n V∞

Number of blades

Blade solidity

Advance ratio

Disk area

Disk loading

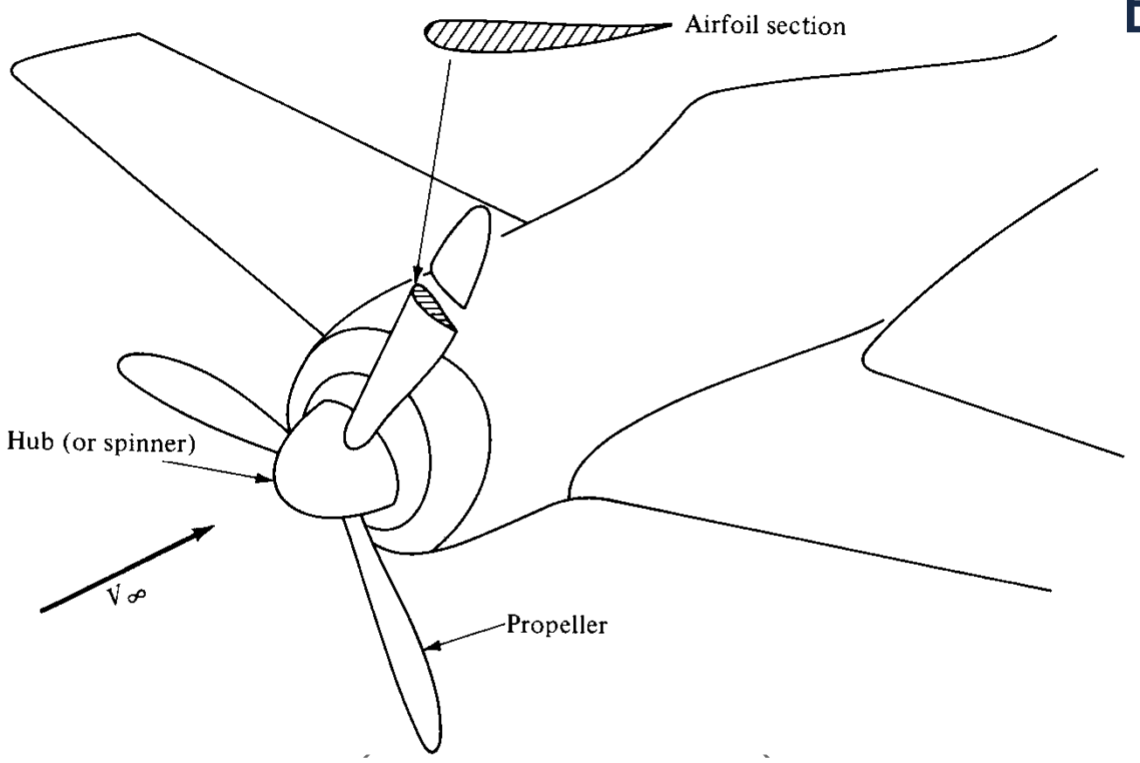
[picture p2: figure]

Blade loading coefficient

B
σ =

Bc
2πR
J =

V
nD

## S = πR²

T/S

## CT /σ

Thrust or thrust coefficient

Torque Q or torque coefficient

Power P or power coefficient

Efficiency

Figure of merit

T | CT =

T

## ρn²D⁴

| CQ =

Q

## ρn²D⁵

| CP =

P

## ρn³D⁵

η =

TV∞
Qω

## FOM =

T
P
| T 2πR²ρ

Anderson, John David. Introduction to flight. New York: McGraw-Hill, 1989.

# Propellers

- For a given airfoil section on a blade, the relative wind is due to a combination of
- The aircraft’s forward motion (inflow velocity normal to the propeller disk plane)
- The propeller’s rotational motion (tangential velocity in the propeller disk plane)

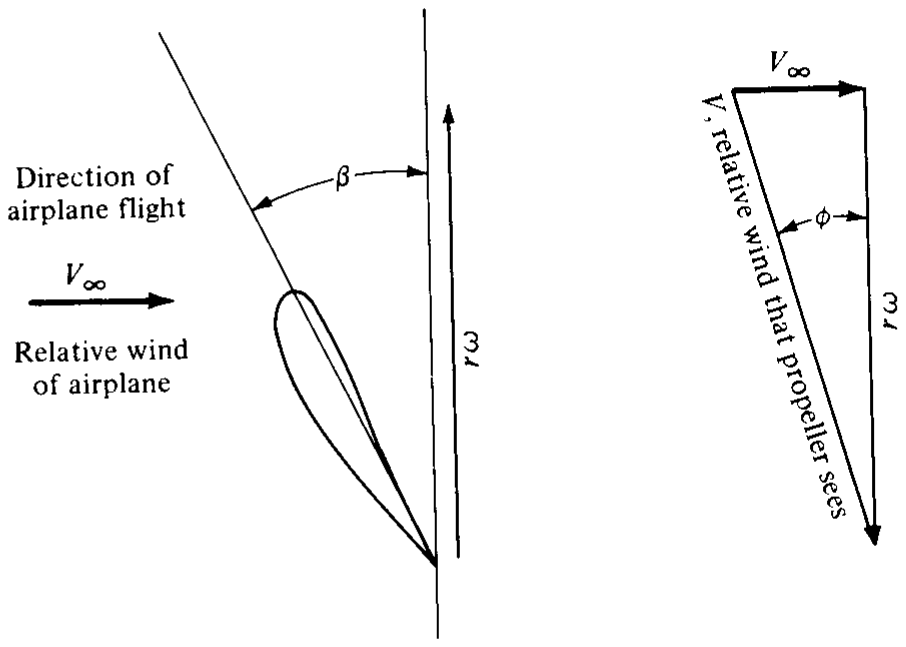
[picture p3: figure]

- : inflow angle (rad)
- : twist angle
- : angle of attack

ϕ
β
α

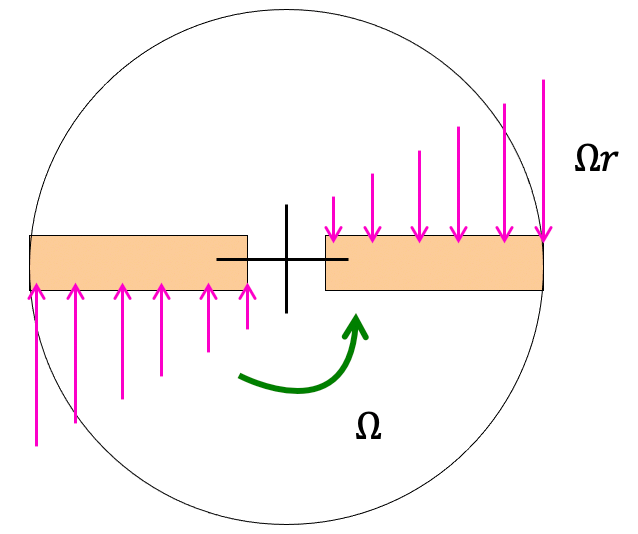
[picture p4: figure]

- : angular speed (rad)
- : rotational speed
- : radius

ω
n
r

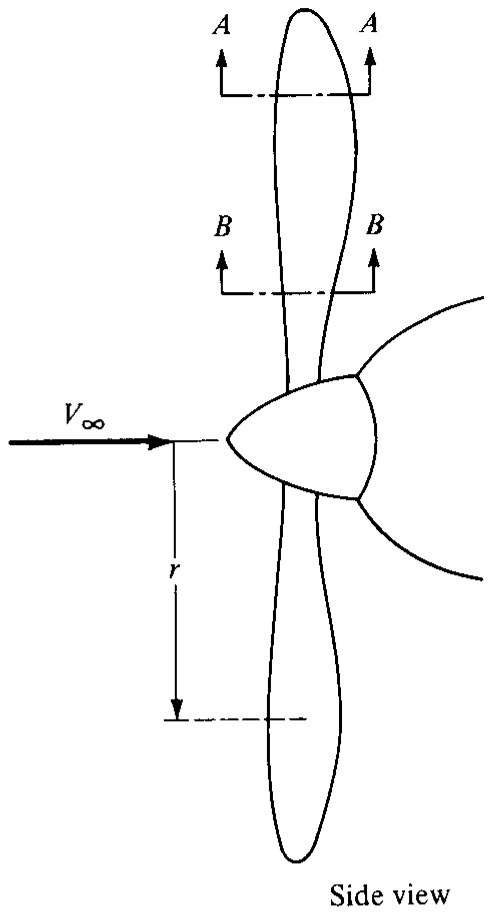
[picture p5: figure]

# Propellers

rω

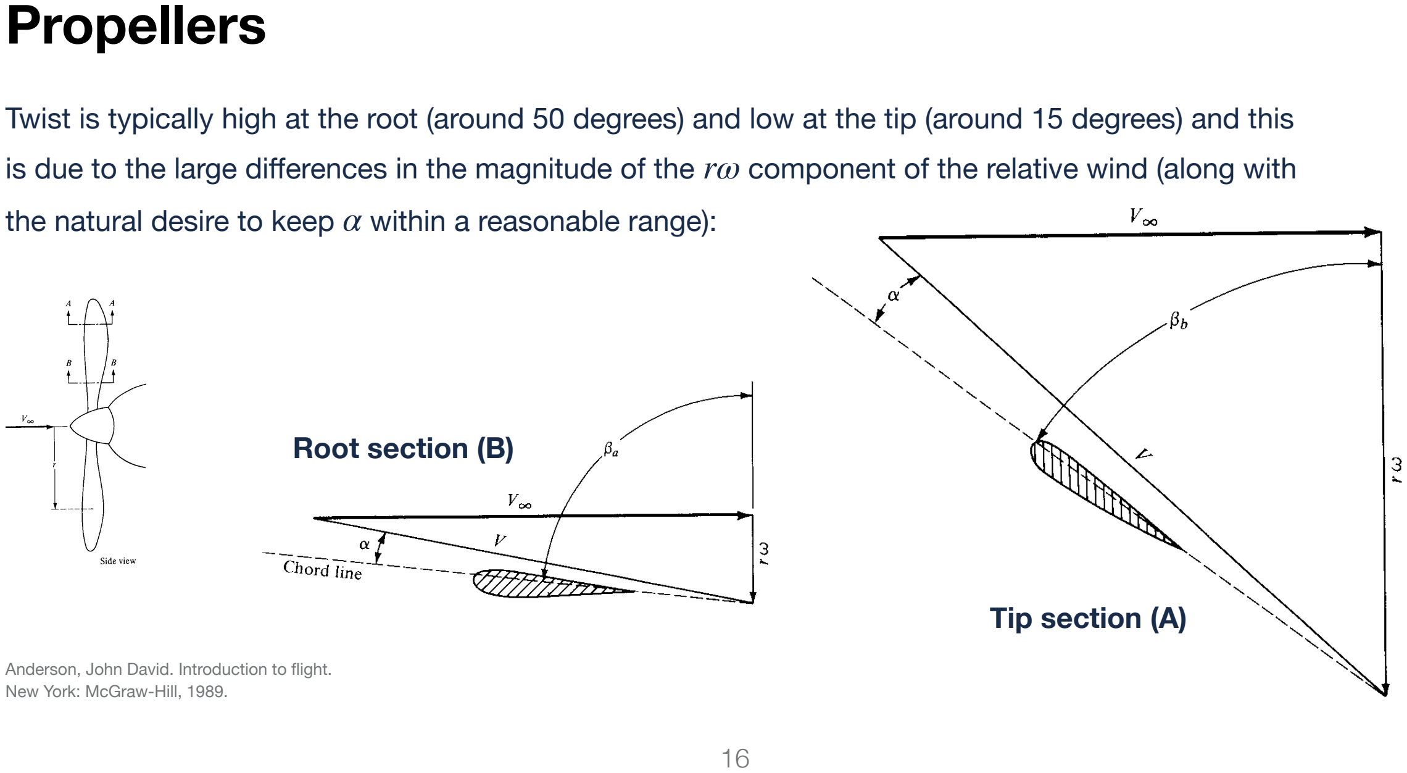
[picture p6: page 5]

Twist is typically high at the root (around 50 degrees) and low at the tip (around 15 degrees) and this is due to the large differences in the magnitude of the component of the relative wind (along with the natural desire to keep within a reasonable range):

α

Anderson, John David. Introduction to flight. New York: McGraw-Hill, 1989.

Root section (B)

Tip section (A)

# Propellers

Advance ratio
For a fixed pitch angle , efficiency is largely a function only of advance ratio , defined as
where is rotational speed and | is diameter.
β | η | J | J =

V
nD
n | D

Efficiency curves with fixed pitch

Efficiency is zero at | because speed is zero.
Efficiency is zero at some | because has
grown so large that lift is zero and so thrust is zero.

J = 0
J > 0 V

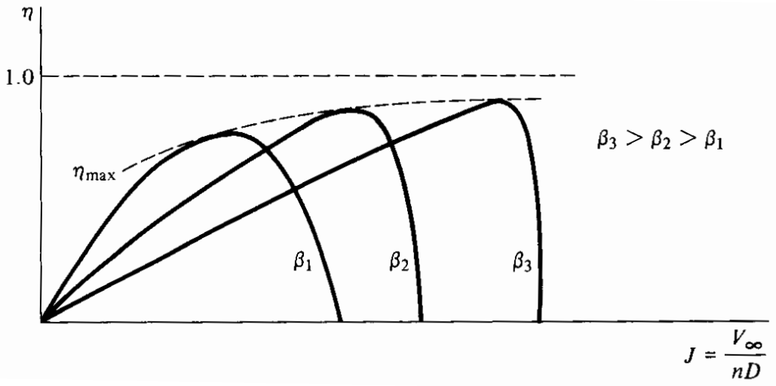
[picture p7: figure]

Anderson, John David. Introduction to flight. New York: McGraw-Hill, 1989.

# Estimating rotor power

We can relate power required by the rotor to thrust, based on the parameters, freestream velocity normal to the rotor disk, air density, and disk area:

where is a parameter that accounts for losses (a reasonable value is 1.2)

Compare this to

## Pdisk = TV∞⊥ + κT −V∞⊥

2

+

V²
∞⊥
4

+

T
2ρAdisk

κ

## FOM =

T
P

T

## 2πR²ρ

Chauhan, S. S., & Martins, J. R. (2020). Tilt-wing eVTOL takeoff trajectory optimization. Journal of aircraft, 57(1), 93-112.

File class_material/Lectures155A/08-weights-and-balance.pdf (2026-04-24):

## John Hwang

Associate Professor

# MAE 155A: Aerospace Engineering Design I

# Weights and balance

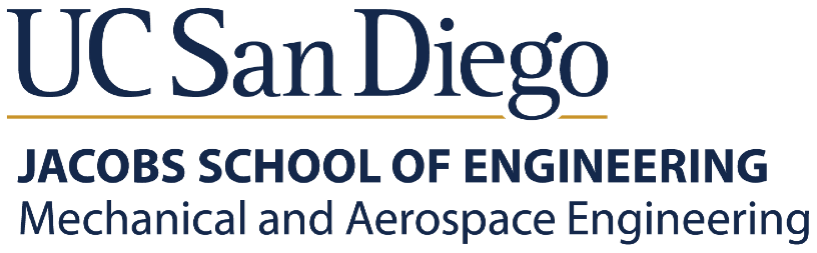
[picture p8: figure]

# Overview

- Previously, we came up with an initial estimate for gross weight:
1. Decomposed gross weight into empty, crew, payload, and fuel/battery weight.
2. Used curve fits of historical data for empty weight fractions.
3. Iteratively solved the resulting coupled equation.
4. Looked at comparable values from previous similar aircraft.
- Now, we will decompose empty weight into the weights of individual aircraft components:
- We will model the component weights as a function of component design parameters (e.g., area and aspect ratio for wings)
- As before, the component weights will be computed using empirical curve fits.
- Breaking the weight down by component enables predicting the location of the center of gravity (CG), which is important for stability analysis.

# Weight build-up

Aircraft design textbooks provide component weight estimation formulas based on historical data. Example—wing weight for GA aircraft (all imperial units):

## Wwing = 0.036S⁰.758

w | W⁰.0035
fw | (
AR

## cos² Λ)

0.6
q⁰.006λ⁰.04

(
100t/c

## cos Λ )

−0.3
(NzWdg)

0.49

- wing area
- fuel weight (carried in the wing)
- aspect ratio
- quarter-chord sweep
- taper ratio
- thickness-to-chord ratio
- dynamic pressure
- ultimate load factor, which is 1.5 times the limit load factor
- flight design gross weight

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
# Weight build-up


Category | Weight group | Fudge factor (multiplier)
Advanced composites | Wing | 0.85-0.90
| Tails | 0.83-0.88
| Fuselage 1 nacelle | 0.90 - 0.95
| Landing gear | 0.95-1.0
| Air induction system | 0.85-0.90
Braced wing | Wing | 0.82
Braced biplane | Wing | 0.6
Wood fuselage | Fuselage | 1.60
Steel tube fuselage | Fuselage | 1.80
Flying boat hull | Fuselage | 1.25
Carrier-based aircraft | Fuselage and landing gear | 1.2-1.3

General aviation- utility
General aviation- aerobatic Homebuilt
Transport
Strategic bomber
Tactical bomber

5
3 to 4
3
4
6.5 to 9
- 2
-1 to -2
- 1
- 2
-3 to - 6

Load factors

Fudge factors: For new configurations, new technologies, or concepts for which there is no historical data available

Raymer, D. (2012). Aircraft design: a conceptual approach. American Institute of Aeronautics and Astronautics, Inc..

# Computing the CG

Aircraft components: wing, horizontal stabilizer, vertical stabilizer, fuselage, main landing gear, nose landing gear, engines, fuel system, flight controls, hydraulics, electrical, avionics, air conditioning, anti-ice, furnishings Procedure:
1. Pick any reference point.
2. Estimate the weight of each component.
3. Select the CG position ( ) of each component in the aircraft frame, relative to the reference point.
4. Compute the aircraft CG relative to the reference point using the formula below.
The moment about the reference point is:

Therefore, we can compute the CG position using:

xcgi

## Wxcg

= ∑
i

Wi

xcgi

xcg

=

∑i
Wi

xcgi
∑i
Wi

# Static stability overview

Here, we are focused on trim and static longitudinal stability.
Trim: Balance of the forces and moments acting on the aircraft.
Static longitudinal stability: Considers whether pitching moments have a tendency to return to equilibrium given disturbances in angle of attack.
Dynamic stability: Considers the behavior of the aircraft over time in response to a disturbance from a steady flight condition.

Dynamically stable; Neutrally stable dynamically; Dynamically unstable

# Center of pressure and aerodynamic center

Pressure coefficient
Cp

=

p − p∞


He, X., Li, J., Mader, C. A., Yildirim, A., & Martins, J. R. (2019). Robust aerodynamic shape optimization—from a circle to an airfoil. Aerospace Science and Technology, 87, 48-61.

Center of pressure (CP): Point about which | .
- The CP is the point at which we can represent a pressure field as a single force with no moment, at a particular flight condition (e.g., angle of attack)
- At all other points, we would have to represent the pressure distribution as a force at the point plus a non-zero moment.

Cm

= 0

Aerodynamic center (AC): Point about which | .
- The AC is the CP of the incremental pressure distribution that results from increasing the angle of attack.
- Since the AC is not the CP in general, the moment is non-zero at the AC.

## dCm

dα

= 0

xac

=

xc
4

+ Δxac Swing

Δxac

= 0.26(M − 0.4)

2.5
, (0.4 ≤ M < 1.1)
Δxac

= 0.112 − 0.004M, (M > 1.1)

Raymer, D. (2012). Aircraft design: a conceptual approach. American Institute of Aeronautics and Astronautics, Inc..

# Neutral point

Neutral point (NP): This is the AC of the entire aircraft.

The total moment acting on the aircraft is given by

Dividing through by , the total moment coefficient becomes:

Taking the derivative with respect to with the NP as the reference point, we obtain:

, since | .
Therefore, the neutral point is given by: | .

## CmqSc = ∑

i

# (Cmi

## qSi

## ci − CLi

## qSi

(xaci

− xref)

)

## qSc

Cm

= ∑

i (Cmi
Si
S

ci

## c − CLi

Si
S

xaci

− xref

c )

α

## dCm

dα

= ∑
i

## − dCLi

dα

Si
S

xaci

− xnp
c

= 0

## dCmi

dα

= 0

xnp

=

∑i

dCLi
dα

Si

xaci
∑i

dCLi
dα

Si

# Tail lift-curve slope

xnp

=

∑i

dCLi
dα

Si

xaci
∑i

dCLi
dα

Si

Lifting surfaces downstream of others have modified lift-curve slopes because of downwash. Consider the horizontal tail:

For the tail efficiency factor | , 0.90 is a typical value.

Taking the derivative with respect to angle of attack,

## CLt

= [

## CLt0

+

## dCLt dαt

(α + i

t − ϵ)

] ηh

ηh =

qh
q

## dCLt

dα

=

## dCLt

## dαt (¹ ⁻ dϵ

## dα) ηh

# Tail downwash

Tai l Geometry; Wing; Zero lift angle of attack

Raymer, D. (2012). Aircraft design: a conceptual approach. American Institute of Aeronautics and Astronautics, Inc..

# Static margin

Typical values for GA aircraft are 10-20%.
CG excursion: Range of CG variation due to crew, fuel, and payload (passengers). For GA aircraft, the CG location varies up to 25%. For stability, we must maintain at least 5% static margin.

SM =

xnp − xcg

## mac

Gross weight; Take off; e.g. location, % M.A.C. from Datum

Raymer, D. (2012). Aircraft design: a conceptual approach. American Institute of Aeronautics and Astronautics, Inc..

# Estimating tail sizing

Sailplane; Homebuilt; Twin turboprop; Flying boot; Jet trainer; Jet fighter; Military cargoj bomber; Jet transport; Typical values; Horizontal cHr; Vertical Cvr

Horizontal and vertical tail volume coefficients:

where the subscripts and stand for the horizontal and vertical stabilizer, respectively.

ch =

## LhSh cwSw

and cv

=

## LvSv bwSw

h v

Raymer, D. (2012). Aircraft design: a conceptual approach. American Institute of Aeronautics and Astronautics, Inc..

Note: are the moment arms, measured from the quarter chord location of the wing to that of the corresponding stabilizer surface

L*

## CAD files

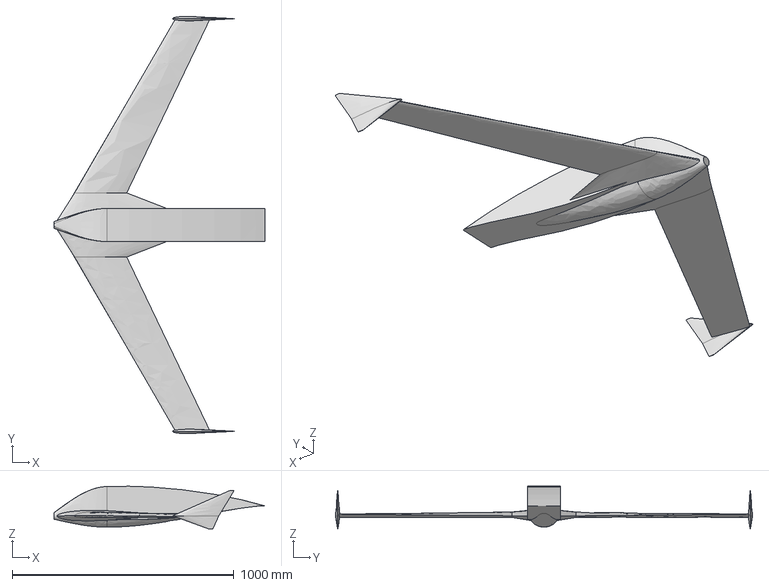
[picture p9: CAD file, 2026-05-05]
CFD/CFD Model.step
950.0 x 1880.6 x 192.1 mm

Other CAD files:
CFD/Nimbus_CFD_OML.step

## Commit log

2026-04-21 No more x foil ✅
2026-04-22 Add CLAUDE.md, CodeGen workflow, and class materials
2026-04-23 Change V-n diagram units to m/s and fix x-axis label
2026-04-23 Vp = 2900 cm^3
2026-04-24 Add dynamic stability AVL pipeline and reorganize class materials
    - Add src/Stability/dynamicStabilityAVL.m: full 5-step dynamic stability
    pipeline (write AVL files, run AVL, parse ST, dimensionalize in SI,
    build Along/Alat, eigenanalysis, MIL-F-8785C handling quality report)
    - Add dynamic stability integration block in main.m with cross-platform
    AVL executable detection (avl352 on Mac, avl.exe on Windows)
    - Add AVL/ folder with scripts and Mac executable
    - Reorganize class_material/ into Lectures155A/ and Lectures155B/ subfolders
2026-04-24 Fix dynamic stability bugs: theta0, elevon placement, and Mach
    - Fix theta0=0 bug: pitch angle now correctly set to alpha_trim_deg
    for level cruise (gamma=0 => theta=alpha)
    - Fix AVL elevon CONTROL card placement: cards were after eta0.90 and
    tip sections, making elevon span eta0.90→tip instead of eta0.60→eta0.90
    Fixed by placing CONTROL after eta0.60 and eta0.90 sections
    - Add computed Mach number to AVL geometry header (was hardcoded 0.0)
    Mach = V/a_sl = 26/340.3 = 0.076
    - Improve readability of all generated AVL files (geometry, mass, run)
2026-04-24 Fix AINC sign in write_geom: use -alphaL0 so wing produces lift
    AInc = -alphaL0_deg (positive) correctly tilts NACA 0012 sections so
    their zero-lift direction matches the cambered airfoil. The previous
    sign (+alphaL0_deg) caused CLtot = -0.04 (downforce).
2026-04-24 Add below-wing fin portion to AVL geometry model
    verticalSurfaceDesign splits the fin into topFrac above and
    (1-topFrac) below the wing mount. Previously write_geom only
    modeled the above-wing portion, missing 34% of the fin area.
    Now each fin is split into two SURFACE blocks (Vfin_R_top,
    Vfin_R_bot, Vfin_L_top, Vfin_L_bot). Rudder only on top blocks.
2026-04-24 Add spanwise twist to AVL wing sections; collapse fin to one surface
    Wing: AInc now varies per section as twist(eta) - alphaL0, using
    linear twist from twistOut. Previously all sections used the same
    AInc ignoring the designed washout.
    Fin: collapsed four SURFACE blocks back to two (Vfin_R, Vfin_L),
    each with sections ordered bottom-tip → root → top-tip. AVL
    correctly handles a surface that passes through the root this way.
2026-04-24 Trim geometry file comments to essentials only
    Kept: header (coord system, AInc formula), surface labels,
    elevon/rudder start-end markers. Removed: redundant format
    explanations, per-section z/eta labels, separator bars.
2026-04-24 fixed penalty still in print command
    looks like AVL viewer isnt working for windows b/c wrong file name but i didnt change anything
2026-04-24 Model full spanwise aerodynamic twist and Clα in AVL geometry
    - Replace alphaL0_avg with root/tip interpolation so AInc(η) = twist_geo(η) - alphaL0(η)
    captures both geometric washout (Panknin) and aerodynamic twist (E222→E230 camber variation)
    - Add CLAF per section: spanwise-interpolated 2D lift curve slope written to centerbody
    and wing sections so AVL uses actual E222/E230 Clα instead of thin-airfoil 2π assumption
    - Pass alphaL0_root/tip_deg and Cla_root/tip_per_deg through dynIn → write_geom
2026-04-25 Replace NACA 0012 with actual airfoils (E222/E230/MH95) in AVL geometry
    - Wing sections: E222 (root→elevon inboard), E230 (elevon outboard→tip) via AFILE keyword
    - Centerbody: MH95 fuselage airfoil when modelCenterbody=true
    - AInc now = geometric twist only (alphaL0 removed — camber already in .dat geometry)
    - Add airfoilFuselageFile input with fallback to root airfoil if unset
    - Add modelCenterbody flag to toggle centerbody surface; extend wing to Y=0 when false
    - Remove duplicate root-level e222.dat and mh60.dat files
2026-04-25 Use NACA 0018 for centerbody fuselage section in AVL
2026-04-25 Add xLE_root_m as 7th sweep/optimization variable for NP shift
    Wing LE root x-position is now swept ([0.00, 0.35] m) and included in the
    CMA-ES optimizer, allowing the solver to slide the wing aft on the fuselage
    to move the neutral point aft and recover positive static margin.
2026-04-25 Fix AVL airfoil keyword (AFILE) and add EH0009 fuselage airfoil
    Replace incorrect AIRFOIL keyword with AFILE throughout dynamicStabilityAVL.m
    so AVL correctly loads airfoil .dat files rather than trying to parse a path
    as inline coordinates. Add eh0009.dat to the data/airfoils library.
2026-04-25 Add CMA-ES dynamic stability optimization with MIL-STD HQ constraints
    - dynamicStabilityAVL: add verbose flag to suppress all printout during sweep/optimization
    - dynamicStabilitySweep: suppress AVL output per iteration, slim per-iter print to SM/SP/PH/DR/HQ columns
    - optimizeDynamicStability: add optional lambda override for larger population size
    - stabilityObjective: restructure objective to prioritize longitudinal stability and controllability; cap SM reward at 20%; add Dutch roll penalty; add physical fin height constraint (50% semispan); fix verbose=false on AVL calls
    - main.m: update sweep/optimizer bounds (xLE_root, AR_v), correct fin structural mass to 0.104 kg (scaled from AR_v=2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
2026-04-25 Apply CMA-ES optimized geometry to baseline and guard sweep/optimizer flags
    Wing: sweep 30→22.7 deg, taper 0.85→0.702, xLE_root 0.0822→0.1300 m
    Fins: AR_v 2.0→2.41, taper 0.60→0.400, sweep 30→40.7 deg
    Fin mass: 0.104→0.048 kg (corrected for AR_v=2.41)
    Wrap dynamicStabilitySweep in runSweep=false guard (same pattern as optimizer)
    Stability result: SM=8.3% MAC, SP zeta=0.40 (L1), PH zeta=0.002 (L2), DR zeta=0.15 (L2)
2026-04-26 Add control surface sizing and fix rudder yaw authority
    - Parse AVL control derivatives (CLde, Cmde, Clda, Cnda, CYdr, Cndr,
    Cm0_trim) from ST file and expose via dynOut.controlDerivs
    - New controlSurfaceSizing.m: trim deflection, max load factor, min
    turn radius, roll rate, and rudder yaw moment from AVL derivatives
    - Fix rudder gain on left fin: was -1 (forces cancelled → Cndr=0),
    changed to +1 so both fins add → non-zero yaw authority
    - Results: trim=+6.44 deg, n_max=1.78g, phi_max=55.8 deg,
    R_min=46.8 m, roll rate=188 deg/s, rudder Cndr=0.000017/deg
2026-04-26 Add rudder chord fraction as 4th CMA-ES design variable in control surface optimizer
    x(4) = rudder_cf optimized alongside elevon geometry. Objective gains
    a soft penalty (up to 30 m equiv.) when rudder Cn authority is
    insufficient to overcome aileron adverse yaw. Stale grid-search
    fields removed from main.m csOptIn block.
2026-04-26 Apply CMA-ES optimized control surface geometry to baseline
    Elevon: chord_frac=0.450, eta=[0.300, 0.749] — turn radius 46.8→25.6 m,
    trim 6.4→6.0 deg, roll rate 343 deg/s. Rudder: cf=0.500 (bound-limited;
    Cn_ratio=0.38, fin area constrains adverse-yaw authority).
2026-04-26 Add shaded elevon and rudder patches to 3D geometry plot
    Elevon (orange) and rudder (blue) patches drawn from control surface
    geometry parameters. Hinge lines shown on each surface. Toggled via
    geom3DIn.plotControlSurfaces (default false, set true in main.m).
2026-04-27 Add full aircraft profit optimizer and Monte Carlo sensitivity analysis
    - Add CMA-ES profit optimizer (profitOptimization.m): 11 design variables,
    full AVL dynamic stability per evaluation, fuselage Swet scaling with Vp^(2/3)
    - Add Monte Carlo profit sensitivity analysis (monteCarloProfitSensitivity.m)
    - Switch airfoil to MH61 (reflexed flying wing, Cm0=-0.012 vs E222 Cm0=-0.081)
    - Update run flags: runProfitOpt, runMonteCarlo added to main.m
    - Optimizer bounds tuned across 4 runs; best result J=5.03 $/hr at Vp=6L
2026-04-27 Just a few corrections
    Wp must be less (I cnaged it back to 800g) to be able to take off thrust available
    Vp we changed back to cad but now if these sise wings are going to work maybe I can figure out how to make fuselage bigger for a bigger Vp
    I didnt chane it back yet But i'm not sure whats up with airfoils and wing twist
2026-04-29 Update geometry to profit optimizer result with delta winglets
    - Apply latest profit optimizer: AR=5.124, taper=0.661, sweep=28.3°, xLE=0.0908 m
    - Reduce fin volume coeff Cv from 0.04 to 0.02 to enable delta winglet geometry
    - Set delta winglet baseline: AR_v=1.5, taper=0.10, sweep=65°
    - Bypass Panknin root twist in stability optimizer — direct tip twist input
    - Tighten SM upper bound to 13%, target SM=7% in stability and profit optimizers
    - Cap fuselage length at 0.95 m; update Wf/y_root to match optimizer halfwidth
    - Battery at 0.553 m, payload at CG; stability optimizer bounds updated for delta space
2026-04-29 Airfoil fuselage and cargo bay upgrades
2026-04-29 Optimizer result: AR=7.14, Vp=15L, profit=$9.59/hr — lower than previous runs
    Latest CMA-ES result with corrected cargo bay volume formula (area × Wf).
    Fixes: cargoBayGeometry header skip, x-coord frame offset, volume scaling
    with both cb_length² and cb_halfwidth. Battery corrected to 150g. Optimizer
    bounds and x0 seeded from this result for next run.
    Note: profit is lower than previous runs due to corrected volume constraint
    and heavier fuselage CAD mass (1.135 kg from Onshape).
2026-04-30 Update fuselage mass properties from CAD and restore recent work (cargo bay, airfoil selection, optimizer updates)
2026-04-30 Fixed the mess 😵‍💫 but now updating SM and We do still need Harshils code
2026-05-04 some CFD stuff
    [Master Part CFD.step, Nimbus_CFD_OML.step]
2026-05-05 Add optimizer docs and apply climb/turn/winglet constraints to profitOptimization
    - CODE_ARCHITECTURE.txt: full codebase guide for teammate onboarding (579 lines)
    - OPTIMIZATION_EXPLAINED.txt: 10-section optimization writeup for professor presentation
    - profitOptimization.m: add climb T/W and turn T/W hard constraints, winglet root chord
    guard (c_root_v ≤ 1.2 × c_tip), tighten AR_v/sweep bounds, per-generation J/hr column,
    fix wingspan span check to include centerbody halfwidth, update default bounds and x0 seed
    main.m geometry changes intentionally excluded — teammates have active edits there.
2026-05-05 Apply CS optimizer results and add mission-derived maneuver constraints
    - main.m: elevon moved inboard (η: 0.617→0.309, η_end: 0.949→0.759), chord 45%;
    rudder cf updated to 0.493 (optimizer max — Cndr≈0 on 65° delta winglet);
    CS opt constraints now computed from mission params (R_phys, p_ss=70 deg/s)
    - optimizeControlSurfaces.m: p_ss_min default 100→70 deg/s (48° bank in 1 s × 1.5
    margin); add R_min_max_m hard reject (mission turn radius at cruise)
    Note: delta winglet at 65° sweep produces Cndr≈0 — rudder has no yaw authority
    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
2026-05-05 uhh extra stuff
    [CFD Model.step]
2026-05-05 Remove rudder — delta winglet geometry gives Cndr≈0, no yaw authority
    CS optimizer confirmed Cndr = 0.000003/deg (effectively zero) with 65° swept
    delta winglet. Rudder adds servo weight and mechanical complexity for no benefit.
    Yaw handled by differential elevon. vertIn.rudder.enable set to false.
2026-05-05 Ignore .vscode/ — machine-specific IDE settings should not be tracked
2026-05-05 Re-enable rudder — kept for yaw authority pending fin geometry fix
2026-05-05 Onshape vars for claude to track
